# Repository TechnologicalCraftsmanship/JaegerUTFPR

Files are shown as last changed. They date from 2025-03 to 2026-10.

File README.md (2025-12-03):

# Jaeger UTFPR Project Repository

This repository organizes all project files related to the **Jaeger** system, developed as part of ongoing research at **UTFPR**. It includes mechanical parts, electronic fabrication files, embedded system workspaces, and a VR application.

---

## 📂 Folder Structure

.

├── 3d_Models

│   └── models

├── Fabrication

│   ├── Jaeger_5_Rev1

│   │   └── gerber

│   └── Jaeger_Driver_3_Rev1

│       └── gerber

├── JaegerUTFPR_Workspace

│   └── MainProject

└── VR_Application

---

## 📁 Folder Descriptions

### `3d_Models/`
Contains all mechanical 3D models designed for the project that must be printed.

- `models/`: Subfolder holding specific 3D models

---

### `Fabrication/`
Houses the PCB designs and manufacturing files for the Jaeger hardware components.

- `Jaeger_5_Rev1/`: Files related to **Jaeger 5 Revision 1**, which include schematic diagrams and layout files.
  - `gerber/`: Exported Gerber files for PCB fabrication of **Jaeger 5 Rev1**.
  
- `Jaeger_Driver_3_Rev1/`: Files related to **Jaeger Driver 3 Revision 1**, responsible for driving specific modules or actuators.
  - `gerber/`: Exported Gerber files for PCB fabrication of **Jaeger Driver 3 Rev1**.

---

### `JaegerUTFPR_Workspace/`
This folder is the workspace for embedded development, using ESP-IDF.

- `MainProject/`: The main embedded firmware source code, configuration files, and dependencies for the Jaeger system.

---

### `VR_Application/`

Contains the virtual reality application developed for project visualization, simulation, or remote monitoring. This include **Unity** project files, assets, and scripts for interacting with the Jaeger system in a 3D environment.

---

## 🚀 Purpose
This repository aims to centralize all essential components of the Jaeger project, ensuring easy access and version control across mechanical design, hardware development, firmware programming, and VR visualization.

---

## 📝 License

This project is licensed under the [MIT License](LICENSE).

## 📚 Citation

If you use this project or the Jaeger system in your research, please cite the following paper:

> Monteiro et al., "Design and implementation of an open-source, low-cost remote-controlled tiny humanoid robot for accessible robotics applications," *Robotica*, pp. 1–18, 2025.  
> **DOI:** [https://doi.org/10.1017/S0263574725102907](https://doi.org/10.1017/S0263574725102907)

**BibTeX:**

```bibtex
@article{Monteiro2025,
  title={Design and implementation of an open-source, low-cost remote-controlled tiny humanoid robot for accessible robotics applications},
  author={Pivaro Monteiro, Marcos Eduardo and dos Santos, Eduardo Nunes and Pigatto, Daniel Fernando and Alves Junior, Joilson and Ramalho, Leonardo Lira and Issicaba, Diego},
  journal={Robotica},
  year={2025},
  pages={1–18},
  doi={10.1017/S0263574725102907}
}

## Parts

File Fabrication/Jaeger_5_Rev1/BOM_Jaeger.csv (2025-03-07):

ID | Name | Designator | Footprint | Quantity | Manufacturer Part | Manufacturer | Supplier | Supplier Part | Price
1 | B2B-XH-A | X1 | B2B-XH-A | 1
2 | OV2640 FPC | FPC1 | OV2640 FPC 24P | 1 | AFC01-S24FCA-00 | JUSHUO | LCSC | C262669 | 0.113
3 | 1.25T-1-2AW | MIC,SPK | CONN-TH_1.25T-1-2AW | 2 | 1.25T-2AW | BOOMELE(博穆精密) | LCSC | C10832 | 0.015
4 | 220uF | C23,C24 | CAP-TH_BD5.0-P2.00-D0.8-FD | 2 | SK100M035B070A | CapXon | LCSC | C62931 | 0.015
5 | 100uF | C5 | CAP-TH_BD5.0-P2.00-D0.8-FD | 1 | SK100M035B070A | CapXon | LCSC | C62931 | 0.015
6 | 0 | R17 | R0603 | 1 | PTFR0603B10K0P9 | ResistorToday | LCSC | C328421 | 0.107
7 | 15pF | C12 | C0603 | 1 | 10uF | Samsung Electro-Mechanics | LCSC | C15415
8 | 0.1uF | C19,C11,C14,C17,C18,C20,C22,C6,C8,C10,C13 | C0603 | 11 | 10uF | Samsung Electro-Mechanics | LCSC | C15415
9 | ESP32-WROOM-32DC | U1 | WIFIM-SMD_38P-L25.5-W18.0-P1.27 | 1 | ESP32-WROOM-32DC | Espressif Systems | LCSC | C473013
10 | APS6404L-3SQR | U5 | SOP-8_L4.9-W3.9-P1.27-LS6.0-BL | 1 | APS6404L-3SQR | apmemory | LCSC | C9900003441
11 | 10uF | C1,C2,C16,C15,C3,C4,C7 | C0603 | 7 | 10uF | Samsung Electro-Mechanics | LCSC | C15415
12 | 10K | R6,R7,R16,R12,R13,R14,R3,R1 | R0603 | 8 | PTFR0603B10K0P9 | ResistorToday | LCSC | C328421 | 0.107
13 | Button-SMD | RST | SW-SMD_4P-L5.2-W5.2-P3.70-LS6.5 | 1 | 4*4*1.5Copper head,260G, 0.25mm, | BBJ | LCSC | C71830
14 | AMS1117-3.3 | U2,U6 | SOT-223-3_L6.5-W3.4-P2.30-LS7.0-BR | 2 | AMS1117-3.3 | AMS | LCSC | C6186 | 0.153
15 | 4.7K | R4,R5 | R0603 | 2 | PTFR0603B10K0P9 | ResistorToday | LCSC | C328421 | 0.107
16 | 0.1Ohm | R8,R9 | R0603 | 2 | PTFR0603B10K0P9 | ResistorToday | LCSC | C328421 | 0.107
17 | Header-Male-2.54_1x5 | H3 | HEADER-MALE-2.54_1X5 | 1
18 | AO3401A | Q2,Q1 | SOT-23-3_L2.9-W1.6-P1.90-LS2.8-BR | 2 | FDN340P | FAIRCHILD | LCSC | C75469 | 0.166
19 | 1uF | C9,C21 | C0603 | 2 | 10uF | Samsung Electro-Mechanics | LCSC | C15415
20 | 100K | R10 | R0603 | 1 | PTFR0603B10K0P9 | ResistorToday | LCSC | C328421 | 0.107
21 | 1K | R11 | R0603 | 1 | PTFR0603B10K0P9 | ResistorToday | LCSC | C328421 | 0.107
22 | LM358 | U9 | SOP-8_L4.9-W3.9-P1.27-LS6.0-BL | 1 | LM358 | KEXIN(科信) | LCSC | C369938 | 0.052
23 | 3.6 ZMM | D1 | LL-34_L3.5-W1.5-RD | 1 | ZMM22-M | ST(先科) | LCSC | C8073 | 0.018
24 | 1K | R2,R15 | R0603 | 2 | AECR0603F1R00T9 | ResistorToday | LCSC | C328344 | 0.001
25 | XC6206P282MR | U3 | SOT-23-3_L2.9-W1.6-P1.90-LS2.8-BR | 1 | XC6206P282MR | TOREX | LCSC | C14255 | 0.115
26 | XC6206P122MR | U4 | SOT-23-3_L2.9-W1.6-P1.90-LS2.8-BR | 1 | XC6206P122MR-G | Torex Semicon | LCSC | C424699 | 0.114
27 | Header-Male-2.54_1x8 | H1 | HDR-TH_8P-P2.54-V-M | 1 | 210S-1*8P L=11.6MMGold-plated black | Ckmtw | LCSC | C124381 | 0.068

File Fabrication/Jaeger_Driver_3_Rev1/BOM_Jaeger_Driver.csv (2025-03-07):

ID | Name | Designator | Footprint | Quantity | Manufacturer Part | Manufacturer | Supplier | Supplier Part | Price
1 | SH 1mm | H4,H7,H8,H1,H6,H3,H5 | SMD-1.0MM-4P-JST-H2.9 | 7 | SH 1.0mm 4P connector |  | Digi-Key
2 | 1.25T-1-8AW | H3_4,H6_1,H6_7 | CONN-TH_8P-P1.25_1.25T-1-8AW | 3 | 1.25T-1-8AW | BOOMELE | LCSC | C10838 | 0.043
3 | B2B-PH | J2_1,J2_2 | B2B-PH-K-S | 2 | - | JST Sales America | RS-Online
4 | Header-Male-2.54_1x8 | J1 | HDR-TH_8P-P2.54-V-M | 1 | 210S-1*8P L=11.6MMGold-plated black | Ckmtw | LCSC | C124381 | 0.068
5 | 100uF | C25 | CAP-TH_BD5.0-P2.00-D0.8-FD | 1 | SK100M035B070A | CapXon | LCSC | C62931 | 0.015
6 | 10uF | C16,C13,C22,C19,C10,C7,C4,C2 | C0603 | 8 | C0603C104K3NACAUTO | KEMET | LCSC | C141256 | 0.023
7 | 0.01uF | C14,C23,C20,C17,C11,C8,C5,C1 | C0603 | 8 | C0603C104K3NACAUTO | KEMET | LCSC | C141256 | 0.023
8 | 2.2uF | C15,C24,C21,C18,C12,C9,C6,C3 | C0603 | 8 | C0603C104K3NACAUTO | KEMET | LCSC | C141256 | 0.023
9 | DRV8833 | U5,U8,U7,U6,U4,U3,U2,U1 | TSSOP-16EP | 8 | DRV8833PWPR | Texas Instruments | LCSC | C50506 | 0.7
10 | AO3401A | Q16,Q15,Q14,Q13,Q12,Q11,Q10,Q9,Q8,Q7,Q6,Q5,Q3,Q2,Q1 | SOT-23-3_L2.9-W1.6-P1.90-LS2.8-BR_PADSHORT | 15 | FDN340P | FAIRCHILD | LCSC | C75469 | 0.166
11 | AO3401A | Q4 | SOT-23-3_L2.9-W1.6-P1.90-LS2.8-BR_PADSHORT | 1 | FDN340P | onsemi(安森美) | LCSC | C75469 | 0.166
12 | B2B-XH-A | X1 | B2B-XH-A | 1
13 | 0.1Ohm | R9,R1 | R0603 | 2 | PTFR0603B10K0P9 | ResistorToday | LCSC | C328421 | 0.107
14 | 10uF | C26,C29,C27 | C0603 | 3 | 10uF | Samsung Electro-Mechanics | LCSC | C15415
15 | 74HC259D | U9,U11,U10 | SOIC-16_L9.9-W3.9-P1.27-LS6.0-BL | 3 | 74HC259D,652 | Nexperia | LCSC | C546779 | 0.4
16 | AMS1117-5 | U15,U16 | SOT-223-3_L6.5-W3.4-P2.30-LS7.0-BR | 2 | AMS1117-3.3 | AMS | LCSC | C6186 | 0.153

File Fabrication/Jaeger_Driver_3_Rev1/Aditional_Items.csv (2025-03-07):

ID | Name | Reference Link | Quantity
1 | Stepper Motor | https://www.aliexpress.com/item/1005001636602660.html | 7
2 | N20 60rpm DC Motor with reduction | https://www.aliexpress.com/item/1005002870346214.html | 2
3 | OV2640 160deg. Camera. | https://www.aliexpress.com/item/1005004852494122.html | 1
4 | Header-Male-2.54_1x8 | https://www.aliexpress.com/item/32933150164.html | 1
5 | Switch - 10*15mm SPST 2PIN | https://www.aliexpress.com/item/32933150164.html | 1
6 | 16340 Battery Slot | https://www.aliexpress.com/item/1005004821679671.html | 2
7 | 9x7mm Microphone | https://www.aliexpress.com/item/32951244243.html | 1
8 | 2.3cm 2W Speaker | https://www.aliexpress.com/item/32859997207.html | 1

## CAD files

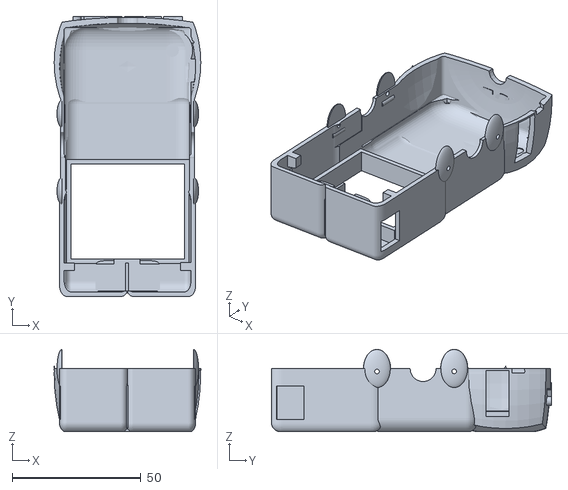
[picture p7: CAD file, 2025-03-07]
3d_Models/models/base_back.stl
57.0 x 108.8 x 32.0

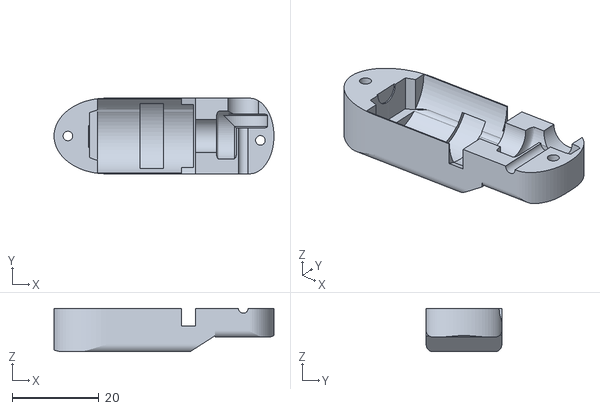
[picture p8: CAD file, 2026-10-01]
3d_Models/models_1.0/arm_left_1.stl
50.6 x 17.4 x 10.00

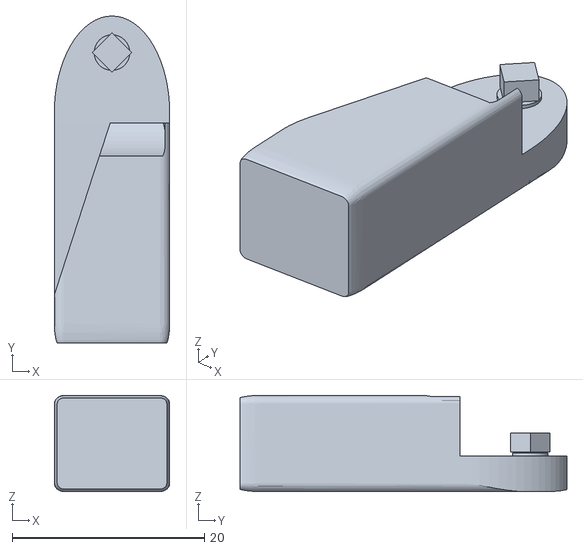
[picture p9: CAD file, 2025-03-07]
3d_Models/models/forearm_left.stl
12.0 x 34.0 x 10.0

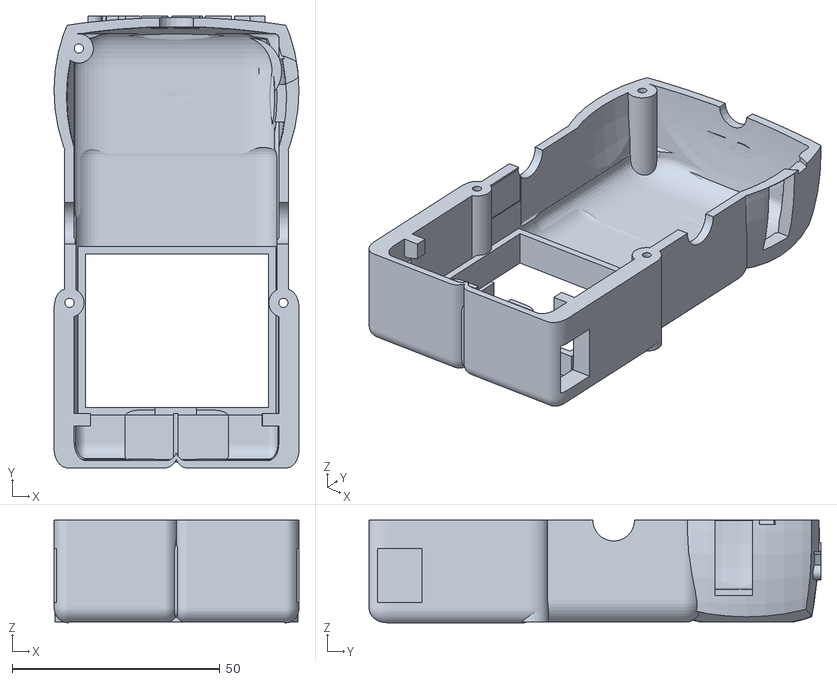
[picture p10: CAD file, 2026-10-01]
3d_Models/models_1.0/base_back.stl
59.0 x 108.8 x 24.7

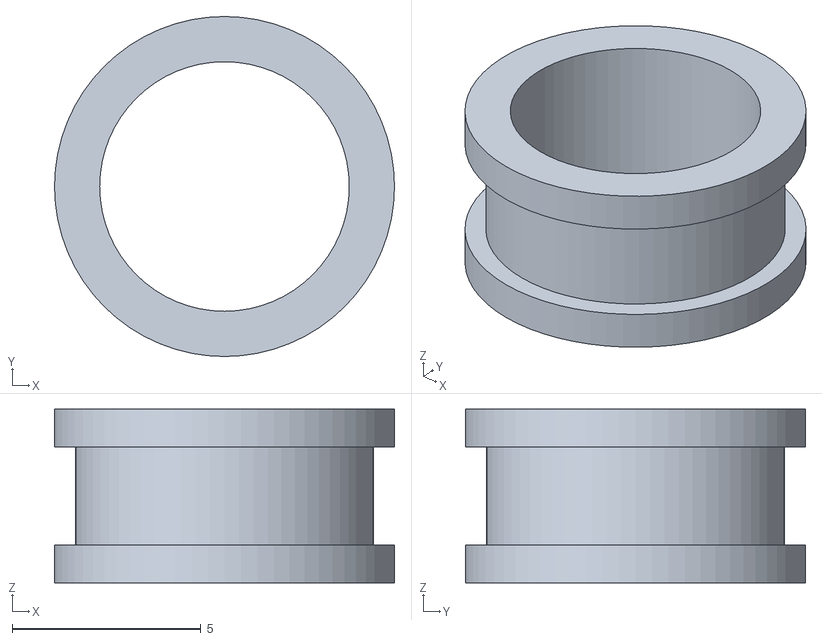
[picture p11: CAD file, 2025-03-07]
3d_Models/models/antenna_support.stl
9.00 x 9.00 x 4.60

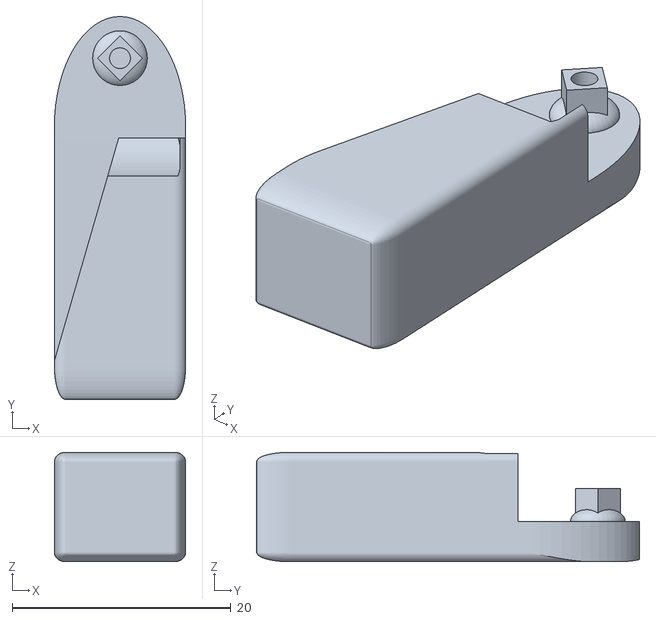
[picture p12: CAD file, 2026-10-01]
3d_Models/models_1.0/forearm_left.stl
12.0 x 35.0 x 10.0

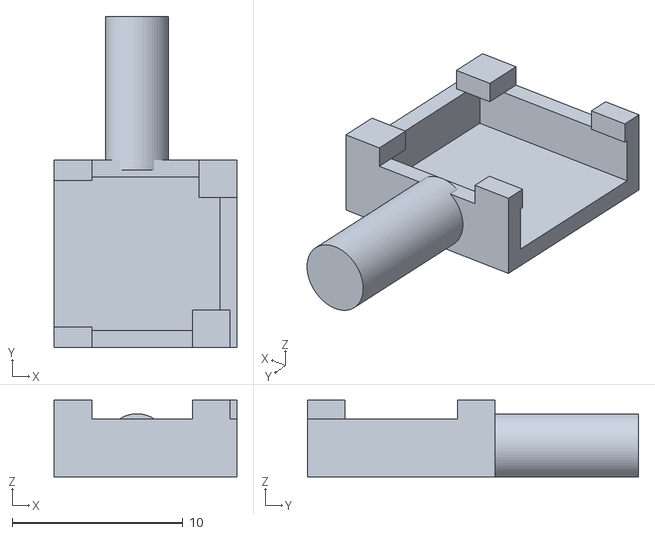
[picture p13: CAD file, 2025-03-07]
3d_Models/models/cam_holder.stl
10.7 x 19.4 x 4.50

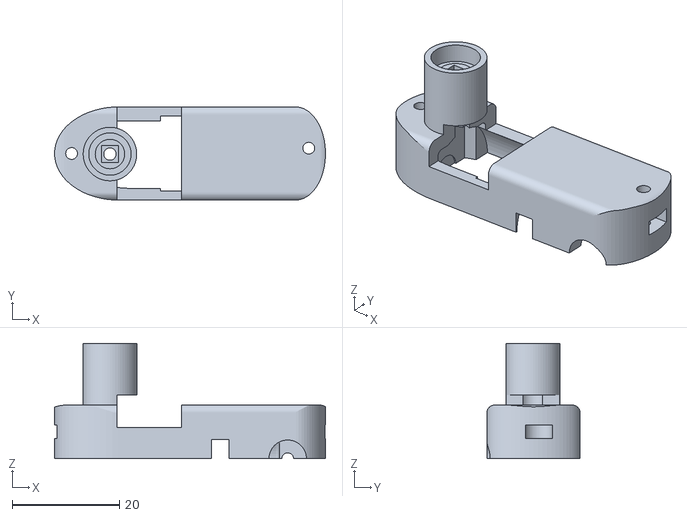
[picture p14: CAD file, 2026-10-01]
3d_Models/models_1.0/arm_right_2.stl
50.6 x 17.4 x 21.5

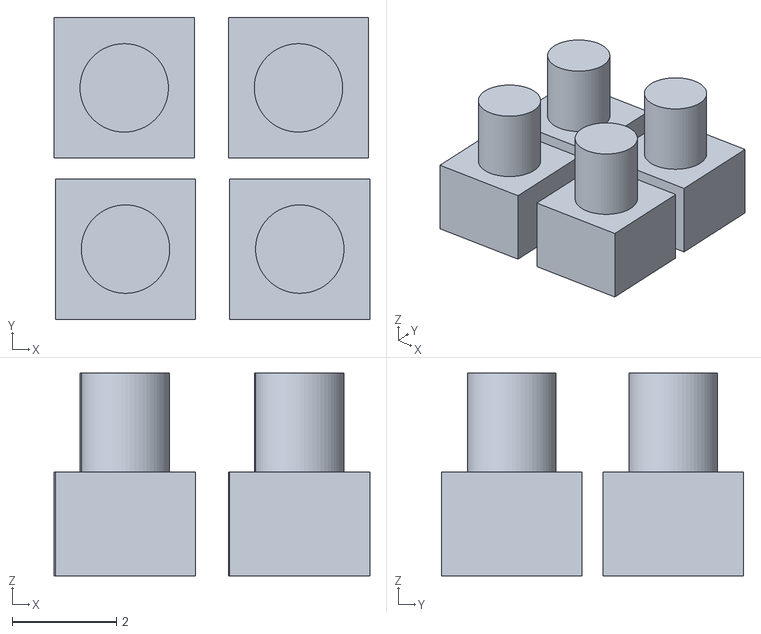
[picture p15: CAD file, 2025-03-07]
3d_Models/models/motor_repair_4x.stl
6.08 x 5.80 x 3.90

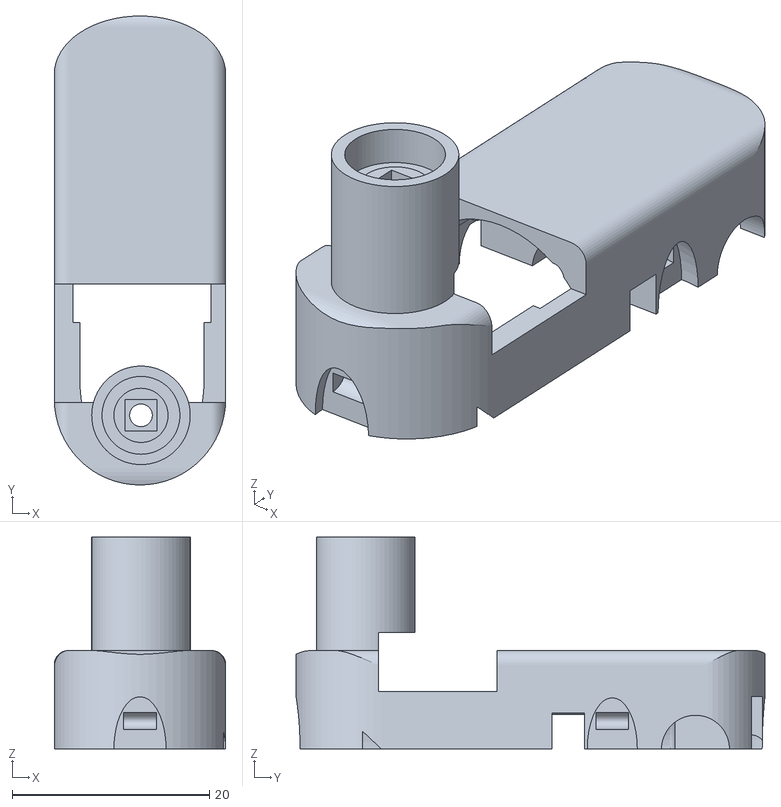
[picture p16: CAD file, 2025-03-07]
3d_Models/models/arm_right_2.stl
17.4 x 47.6 x 21.5

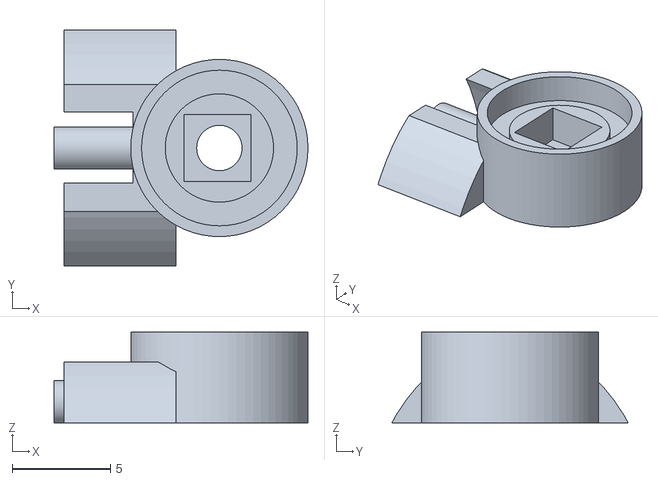
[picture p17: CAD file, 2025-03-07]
3d_Models/models/conForearm.stl
12.9 x 12.0 x 4.60

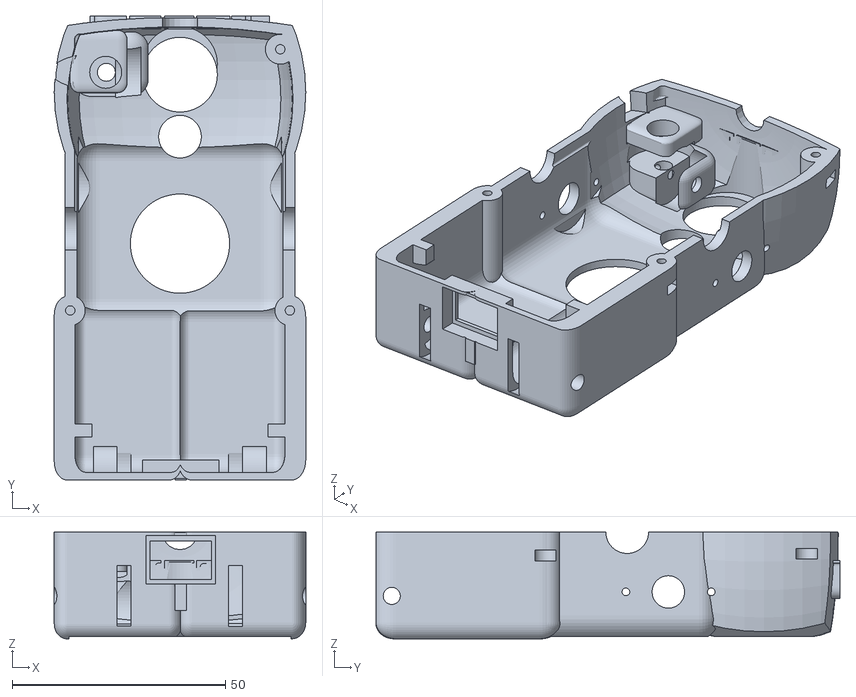
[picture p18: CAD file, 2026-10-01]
3d_Models/models_1.0/base_front.stl
59.0 x 108.8 x 25.0

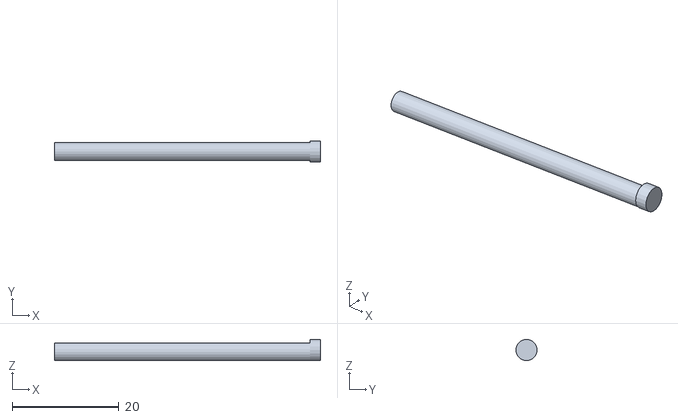
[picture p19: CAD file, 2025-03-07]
3d_Models/models/conWheels.stl
49.8 x 4.00 x 4.00

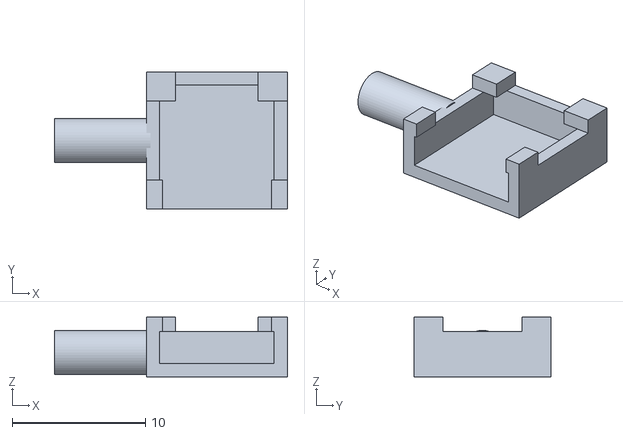
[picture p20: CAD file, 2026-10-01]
3d_Models/models_1.0/cam_holder.stl
17.5 x 10.3 x 4.50

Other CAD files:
3d_Models/models_1.0/arm_left_2.stl
3d_Models/models_1.0/arm_right_1.stl
3d_Models/models_1.0/forearm_right.stl
3d_Models/models/forearm_right.stl
3d_Models/models/arm_left_1.stl
3d_Models/models/arm_left_2.stl
3d_Models/models/arm_right_1.stl
3d_Models/models/base_front.stl
3d_Models/models/cam_holder_wheel.stl
3d_Models/models/cam_mot_wheel.stl
3d_Models/models/wheels.stl

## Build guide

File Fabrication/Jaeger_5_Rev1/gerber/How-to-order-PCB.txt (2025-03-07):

How to Order PCB

Please refer to:
https://docs.easyeda.com/en/PCB/Order-PCB

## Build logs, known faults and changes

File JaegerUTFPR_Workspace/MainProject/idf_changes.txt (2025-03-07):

Não funcionou:
//C:/Espressif/frameworks/esp-idf-v4.4.4\components\lwip\port\esp32\netif\wlanif.c(87): netif->mtu = 4400;
//C:/Espressif/frameworks/esp-idf-v4.4.4\components\lwip\port\esp32\netif\ethernetif.c(83): netif->mtu = 4400;
//C:/Espressif/frameworks/esp-idf-v4.4.4\components\lwip\lwip\src\netif\bridgeif.c(497): netif->mtu = 4400;
//C:/Espressif/frameworks/esp-idf-v4.4.4\components\lwip\lwip\src\netif\slipif.c(79): #define SLIP_MAX_SIZE 4400

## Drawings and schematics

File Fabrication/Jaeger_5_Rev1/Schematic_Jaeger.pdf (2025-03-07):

Microcontroller | Camera Header

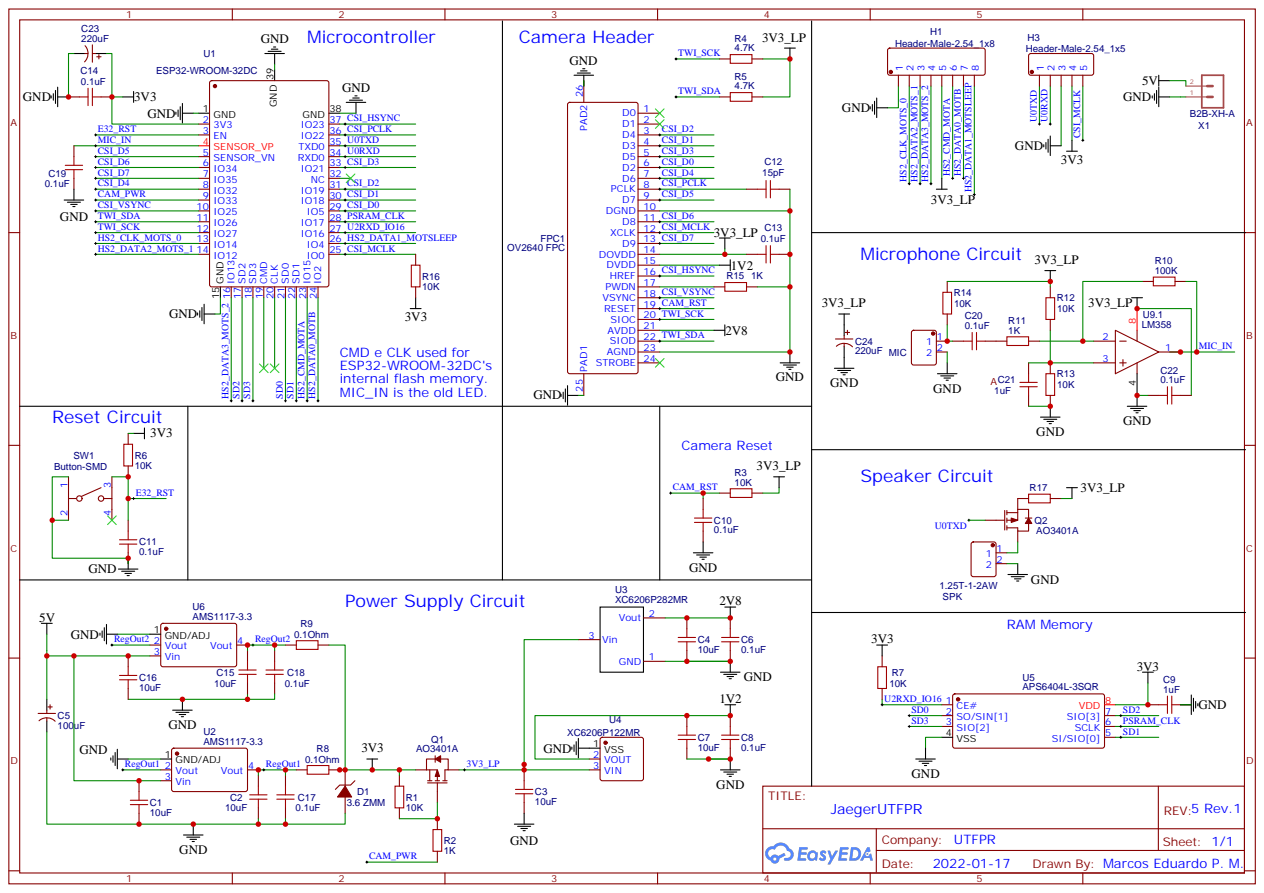
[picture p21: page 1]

IO0 25 IO² 24 IO¹⁵ 23 SD¹ 22 SD⁰ 21 CLK 20 CMD 19 SD³ 18 SD² 17 IO¹³ 16 GND 15

HS2_CMD_MOTA
CMD e CLK used for
ESP32-WROOM-32DC's
internal flash memory.
MIC_IN is the old LED.

Drawn By: Marcos Eduardo P. M.

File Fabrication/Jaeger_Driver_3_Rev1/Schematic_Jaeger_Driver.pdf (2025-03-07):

Motor 1 | Motor 2

# Motor 3

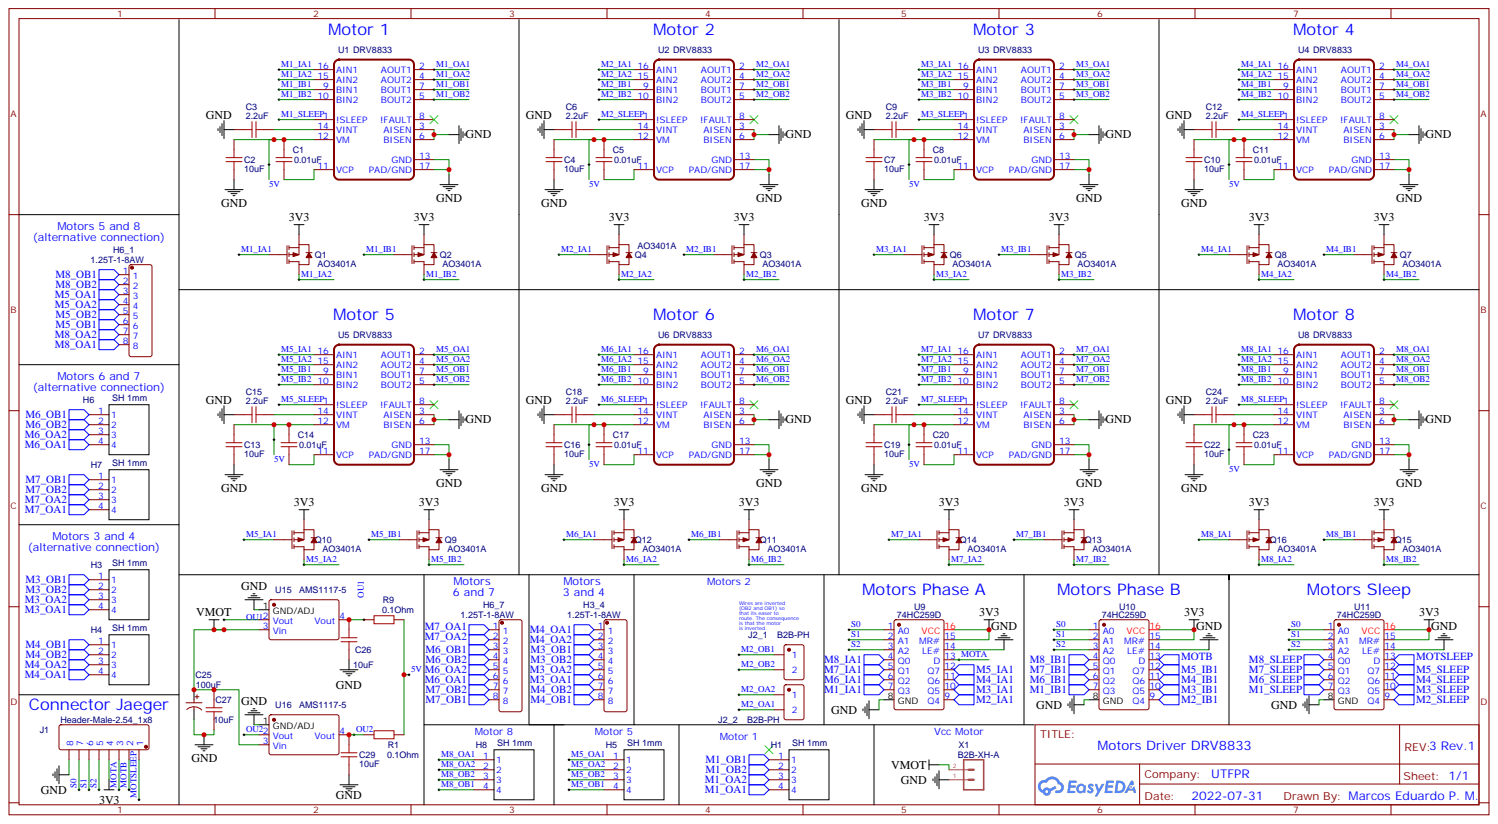
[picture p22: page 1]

Wires are inverted
(OB2 and OB1) so
that its easer to
route. The consequence
is that the motor
is inverted.

Drawn By: Marcos Eduardo P. M.

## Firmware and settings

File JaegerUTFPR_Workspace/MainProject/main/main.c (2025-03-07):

/**
 * This example takes a picture every 5s and print its size on serial monitor.
 */

// =============================== SETUP ======================================

// 1. Board setup (Uncomment):
// #define BOARD_WROVER_KIT
// #define BOARD_ESP32CAM_AITHINKER

/**
 * 2. Kconfig setup
 *
 * If you have a Kconfig file, copy the content from
 *  https://github.com/espressif/esp32-camera/blob/master/Kconfig into it.
 * In case you haven't, copy and paste this Kconfig file inside the src directory.
 * This Kconfig file has definitions that allows more control over the camera and
 * how it will be initialized.
 */

/**
 * 3. Enable PSRAM on sdkconfig:
 *
 * CONFIG_ESP32_SPIRAM_SUPPORT=y
 *
 * More info on
 * https://docs.espressif.com/projects/esp-idf/en/latest/esp32/api-reference/kconfig.html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
 */

// ================================ CODE ======================================
#include <esp_log.h>
#include "esp_wifi.h"
#include <esp_system.h>
#include "esp_event.h"
#include <nvs_flash.h>
#include <sys/param.h>
#include "driver/gpio.h"
#include <string.h>

#include "freertos/FreeRTOS.h"
#include "freertos/task.h"
#include "tcpip_adapter_types.h"
#include "protocol_examples_common.h"

// support IDF 5.x
#ifndef portTICK_RATE_MS
#define portTICK_RATE_MS portTICK_PERIOD_MS
#endif

#include "main_project.h"
#include "DataArray.h"
#include "speaker.h"
#include "mic.h"
#include "esp_camera.h"

extern void startCameraServer();
int soundActive = 1;

volatile Connected connected = DISCONNECTED;
char conBuffer[MAX_PACKET];

#if SPEAKER_ON && SPEAKER_RMT
	rmt_speaker_t rmtSpeaker;
#endif

static const char *TAG = "main";

static camera_config_t camera_config = {
    .pin_pwdn = CAM_PIN_PWDN,
    .pin_reset = CAM_PIN_RESET,
    .pin_xclk = CAM_PIN_XCLK,
    .pin_sscb_sda = CAM_PIN_SIOD,
    .pin_sscb_scl = CAM_PIN_SIOC,

    .pin_d7 = CAM_PIN_D7,
    .pin_d6 = CAM_PIN_D6,
    .pin_d5 = CAM_PIN_D5,
    .pin_d4 = CAM_PIN_D4, //Fixed using define @ main_project.h
    .pin_d3 = CAM_PIN_D3,
    .pin_d2 = CAM_PIN_D2,
    .pin_d1 = CAM_PIN_D1,
    .pin_d0 = CAM_PIN_D0,
    .pin_vsync = CAM_PIN_VSYNC,
    .pin_href = CAM_PIN_HREF,
    .pin_pclk = CAM_PIN_PCLK,

    //XCLK 20MHz or 10MHz for OV2640 double FPS (Experimental)
    .xclk_freq_hz = 20000000,
    //.ledc_timer = LEDC_TIMER_0,
    //.ledc_channel = LEDC_CHANNEL_0,

    //.pixel_format = PIXFORMAT_RGB565, //YUV422,GRAYSCALE,RGB565,JPEG
    .pixel_format   = PIXFORMAT_JPEG,
    .frame_size = FRAMESIZE_SVGA, // 800x600 //FRAMESIZE_SVGA,    //QQVGA-UXGA Do not use sizes above QVGA when not JPEG

    .jpeg_quality = 9, //0-63 lower number means higher quality
	//5 = ~48kb
	//9 = ~19kb
    .fb_count = 2,       //if more than one, i2s runs in continuous mode. Use only with JPEG
    .grab_mode = CAMERA_GRAB_WHEN_EMPTY,
};

static esp_err_t init_camera()
{
    //initialize the camera
    esp_err_t err = esp_camera_init(&camera_config);
    if (err != ESP_OK)
    {
    	//_ESP_LOGI(TAG, "Camera Init Failed");
        return err;
    }
    //LOG_LOCAL_LEVEL //_ESP_LOG_VERBOSE

    return ESP_OK;
}

static void event_handler(void* arg, esp_event_base_t event_base,
                                int32_t event_id, void* event_data)
{
    if (event_base == WIFI_EVENT && event_id == WIFI_EVENT_STA_START) {
        esp_wifi_connect();
    } else if (event_base == WIFI_EVENT && event_id == WIFI_EVENT_STA_DISCONNECTED) {
        esp_wifi_connect();
    } else if (event_base == IP_EVENT && event_id == IP_EVENT_STA_GOT_IP) {
        ip_event_got_ip_t* event = (ip_event_got_ip_t*) event_data;
        //_ESP_LOGI(TAG, "got ip:" IPSTR, IP2STR(&event->ip_info.ip));
    }
}
void setLowPowerPin(uint8_t enable)
{
    gpio_set_direction(CAM_PIN_PWDN, GPIO_MODE_OUTPUT);
    gpio_set_level(CAM_PIN_PWDN, enable); //P-channel: 0 means On and 1 means Off
}
void playTestSound();
void app_main()
{

	//#undef SPEAKER_ON
	//#undef MIC_ON
	//redefine pref. IP to Local
	//@ sdkconfig
	//# CONFIG_EXAMPLE_CONNECT_IPV6_PREF_LOCAL_LINK is not set
	//CONFIG_EXAMPLE_CONNECT_IPV6_PREF_GLOBAL=y

	//@ main_project.h
	////#define CONFIG_EXAMPLE_IPV6 1



	//playTestSound();
	soundActive = 1;

	int cameraStarted = 0;
    //nvs_flash_init();
    //tcpip_adapter_init();

    ////_printf(("1....");
	//Turn off the low power pin so we can use the camera, motors and other resources.
	setLowPowerPin(0);

	//The first thing we must do after turning on VCC motors (and camera) pin is to init the motors so that we make sure they are off
    motorInit();


	///*
	//First, we disable the speaker pin just to make sure it wont be on by default
	forceSpeakerDisable();
	#if SPEAKER_ON && SPEAKER_LEDC
		DataArray speakerArray;
	    dataArrayInit(&speakerArray, SPEAKER_ARRAY_MAX);
	#endif

	#ifdef MIC_ON
	    //Sound Configurations
		DataArray micArray;
		PROJECT_DATA_TYPE *micRawData = malloc(4000);
	    //configure the Mic array and the Speaker Array
	    dataArrayInit(&micArray, MIC_ARRAY_MAX);
	#endif


    ESP_ERROR_CHECK(nvs_flash_init());
	////_printf(("5....");
    ESP_ERROR_CHECK(esp_netif_init());
	////_printf(("6....");

    ESP_ERROR_CHECK(esp_event_loop_init(event_handler, NULL) );
	////_printf(("7....");
    ESP_ERROR_CHECK(example_connect());
	////_printf(("8....");


    if(ESP_OK != init_camera()) {
    	//_ESP_LOGE(TAG, "Camera Failed.\n");
    	cameraStarted = 0;

        ////_ESP_LOGI(TAG, "Camera Ready! Use 'http://");
        //tcpip_adapter_ip_info_t adapterInfo;

        //tcpip_adapter_get_ip_info(0, &adapterInfo); //TCPIP_ADAPTERE_IF_STA = 0
        //char *ip = (char *)&adapterInfo.ip;
        ////_printf((WiFi.localIP());
        ////_ESP_LOGI(TAG, "%d . %d . %d , %d", ip[0], ip[1], ip[2], ip[3]);
        ////_ESP_LOGI(TAG, "' to connect");

        //return;
    } else {
    	cameraStarted = 1;
    }

    start_server();


//*/

    //esp_log_level_set("*", //_ESP_LOG_VERBOSE);

    /*//test with a default sound
    adjustSound(tmpSound, sizeof(tmpSound)/sizeof(SPEAKER_DATA_TYPE));
    dataArrayClearData(&micArray);
    dataArrayWriteFromArrayUINT8_T(&micArray, tmpSound, sizeof(tmpSound)/sizeof(SPEAKER_DATA_TYPE));
	//*/

	#if SPEAKER_ON && SPEAKER_LEDC
    	esp_log_level_set("*", ESP_LOG_ERROR);
			//Configure the LEDC PWM
			initSpeaker(&speakerArray);
	#endif
	#if SPEAKER_ON && SPEAKER_RMT
		//Configure the LEDC PWM
		initSpeaker(&rmtSpeaker);
		//playTestSound(&rmtSpeaker);
		//vTaskDelay(pdMS_TO_TICKS(1000));

    	esp_log_level_set("*", ESP_LOG_ERROR);
#if SPEAKER_PIN ==1 || SPEAKER_PIN ==3
#else
		//esp_log_level_set("*", ESP_LOG_INFO);
#endif
	#endif

	#ifdef MIC_ON
	    //Create the mic task
	    createMicrophoneTask(&micArray);
	#endif

    int64_t fr_start = 0;
    int64_t fr_end = 0;
    int64_t frame_time;


    //int64_t lastExecution = 0;




    while (1)
    {

    	//Sleep in order to let other tasks to process
		vTaskDelay(pdMS_TO_TICKS(40));

    	//if there are free timers
    	if(motorAvailableTimers > 0)
    		verifyMotorQueue();
    	//
        if(connected == CONNECTED)
        {
        	//pastMs += 1000/portTICK_RATE_MS;
///*
#if SPEAKER_ON && SPEAKER_RMT
        	if(soundActive) //only play if the sound is on
        	{
				if(verifyPlaySound(&rmtSpeaker, false))
				{
					//playing sound
				}
        	}
#endif
#ifdef MIC_ON

        	//if we have the sound active and
        	//if there is enough mic data available to send
        	if(soundActive && !playingSound && dataArrayElementsToRead(&micArray) > MIC_SAMPLES_TO_SEND)
        	{
        		////_ESP_LOGI(TAG, "Sending MIC data.");
        		//pastMs = 0;
        		dataArrayReadToArray(&micArray, micRawData, MIC_SAMPLES_TO_SEND);
        		sendRawData(SOUND, micRawData, MIC_SAMPLES_TO_SEND);
        		//continue;
        	}
#endif

        	if(cameraStarted)
        	{
				fr_start = esp_timer_get_time();
				camera_fb_t *pic = esp_camera_fb_get();
				if(pic)
				{
					ESP_LOGI(TAG, "Image start sending.");
					sendCameraImage((void*)pic, 1);
					esp_camera_fb_return(pic);
					ESP_LOGI(TAG, "Image sent.");
					//lastExecution = esp_timer_get_time();
	//				fr_end = esp_timer_get_time();
	//				frame_time = (fr_end - fr_start)/1000;
	//				// use pic->buf to access the image
	//				//_ESP_LOGI(TAG, "%zu with %.1ffps", pic->len, 1000.0 / (uint32_t)frame_time);
				} else {
					ESP_LOGI(TAG, "Could not get image.");
				}
        	}
        } else {
        	vTaskDelay(1000 / portTICK_RATE_MS);
        }
    }
#if SPEAKER_ON && SPEAKER_RMT
    deinitSpeaker(&rmtSpeaker);
#endif
#ifdef MIC_ON
    free(micRawData);
#endif
    motorDeinit();
}

/*
 *
#include "freertos/FreeRTOS.h"
#include "esp_wifi.h"
#include "esp_system.h"
#include "esp_event.h"
#include "esp_event_loop.h"
#include "nvs_flash.h"
#include "driver/gpio.h"
#include "esp_camera.h"

esp_err_t event_handler(void *ctx, system_event_t *event)
{
    return ESP_OK;
}

void app_main(void)
{
    nvs_flash_init();
    tcpip_adapter_init();
    ESP_ERROR_CHECK( esp_event_loop_init(event_handler, NULL) );
    wifi_init_config_t cfg = WIFI_INIT_CONFIG_DEFAULT();
    ESP_ERROR_CHECK( esp_wifi_init(&cfg) );
    ESP_ERROR_CHECK( esp_wifi_set_storage(WIFI_STORAGE_RAM) );
    ESP_ERROR_CHECK( esp_wifi_set_mode(WIFI_MODE_STA) );
    wifi_config_t sta_config = {
        .sta = {
            .ssid = CONFIG_ESP_WIFI_SSID,
            .password = CONFIG_ESP_WIFI_PASSWORD,
            .bssid_set = false
        }
    };

    ESP_ERROR_CHECK( esp_wifi_set_config(WIFI_IF_STA, &sta_config) );
    ESP_ERROR_CHECK( esp_wifi_start() );

    ESP_ERROR_CHECK( esp_wifi_connect() );

    gpio_set_direction(GPIO_NUM_4, GPIO_MODE_OUTPUT);
    int level = 0;
    while (true) {
        gpio_set_level(GPIO_NUM_4, level);
        level = !level;
        vTaskDelay(300 / portTICK_PERIOD_MS);
    }
}

*/

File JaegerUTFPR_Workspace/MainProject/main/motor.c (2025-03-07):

/*
 * Motor.c
 *
 *  Created on: Feb 28, 2022
 *      Author: Thoughtful
 */
#include "sdkconfig.h"
#include "freertos/FreeRTOS.h"
#include "freertos/task.h"
#include "esp_log.h"
#include "esp_wifi.h"
#include "esp_system.h"
#include "esp_event.h"
#include "esp_event_loop.h"
#include "nvs_flash.h"
#include "driver/gpio.h"
#include "hal/gpio_types.h"
//#include "./managed_components/espressif__esp32-camera/driver/include/esp_camera.h"

#include "esp_camera.h"
#include "main_project.h"
#include "driver/rmt.h"
#include "driver/timer.h"

//#include "freertos/semphr.h"

/*

#define DIR_PORT 2
#define STEP_PORT 4
#define MOTOR_SEL0_PORT GPIO_NUM_14
#define MOTOR_SEL1_PORT GPIO_NUM_12
#define MOTOR_SEL2_PORT GPIO_NUM_13
#define MOTOR_SEL3_PORT GPIO_NUM_15
*/

static portMUX_TYPE motorsLock = portMUX_INITIALIZER_UNLOCKED;

static const char *TAG = "motor";

typedef struct MotorTimerTask
{
	bool enabled;
	timer_group_t groupId;
	timer_idx_t timerId;
	int motorId;
	int direction; //1 or -1
	//int ISRSet;
	uint32_t currentStep;
	uint32_t totalSteps;
	uint32_t stepSlowingDown;
	uint32_t initialTimerCount;
	uint32_t currentTimerCount;
	int dcCyclesOn; //used only for DC Motors
	int dcCyclesOff; //used only for DC Motors
	int valueLeftleg; //used only for DC Motors
	int valueRightLeg; //used only for DC Motors
} MotorTimerTask;

#if MOTOR_VERSION == 1
static const float steps_per_rev[12] =
{
		1,  //Used to obtain the information for the left leg
		20 * 165.3817f, //Camera Motor, no reduction
		1,  //DC motors, Used to obtain the information for the right leg
		20 * 165.3817f,
		20 * 165.3817f,
		2210,
		20 * 165.3817f,
		20 * 165.3817f,
		2210,
		1, //Not used
		1 //Not used
};

static const int32_t motorDefaultDirection[12] =
{
		-1,  //Used to obtain the information for the left leg
		1, //Camera Motor
		1,  //DC motor right leg, Used to obtain the information for the right leg
		1, //second motor, right
		-1, //first motor, right arm closer to the shoulder
		-1, //right arm
		-1, //second motor, left arm
		1, //first motor, left arm closer to the shoulder
		1, //left arm
		0, //Not used
		0 //Not used
};
#elif MOTOR_VERSION == 2

static const float steps_per_rev[12] =
{
		1,  //Used to obtain the information for the left leg
		20 * 165.3817f, //Camera Motor, no reduction
		1,  //DC motors, Used to obtain the information for the right leg
		20 * 165.3817f,
		2210,
		2210,
		20 * 165.3817f,
		2210,
		2210,
		1, //Not used
		1 //Not used
};

static const int32_t motorDefaultDirection[12] =
{
		-1,  //Used to obtain the information for the left leg
		1, //Camera Motor
		1,  //DC motor right leg, Used to obtain the information for the right leg
		1, //second motor, right
		-1, //first motor, right arm closer to the shoulder
		-1, //right arm
		-1, //second motor, left arm
		1, //first motor, left arm closer to the shoulder
		1, //left arm
		0, //Not used
		0 //Not used
};
#elif MOTOR_VERSION == 3

static const float steps_per_rev[12] =
{
		1,  //Used to obtain the information for the left leg -> MOTA_PIN -> J2_2
		2210, //Camera Motor
		1,  //DC motors, Used to obtain the information for the right leg -> MOTB_PIN -> J2_1
		2210, //Right Forearm
		2210, //Right arm
		2210, //Right arm, closer to the shoulder
		2210, //Left Forearm
		2210, //Left arm,
		2210, //Left arm, closer to the shoulder
		1, //Not used
		1 //Not used
};

static const int32_t motorDefaultDirection[12] =
{
		-1,  //Used to obtain the information for the left leg
		1, //Camera Motor
		1,  //DC motor right leg, Used to obtain the information for the right leg
		-1,
		-1,
		-1,
		1,
		1,
		1,
		0, //Not used
		0 //Not used
};
#endif

//State of all motors
Motor motors[TOTAL_MOTORS] = { 0 } ;

PinMask motorDirection[MAX_DIRECTION] = {0};
PinMask motorStages[4] = {0};

#define MOTOR_TIMERS_I 1 //1
#define MOTOR_TIMERS_J 2 //2
MotorTimerTask motorTimers[MOTOR_TIMERS_I][MOTOR_TIMERS_J] = {0};
volatile int motorAvailableTimers = 0;
volatile int isMotorRunning = false;
int totalMotorTimers = 0;

MotorState newMotorStates[12] = {0};

//MotorState motors[10] = {0};


int16_t lastRecCentiDegrees[TOTAL_MOTORS] = { 0 } ;

//QueueHandle_t motorQueue;






void configMotorPins()
{

    gpio_config_t io_conf;
    io_conf.intr_type = GPIO_INTR_DISABLE;
    io_conf.mode = GPIO_MODE_OUTPUT;
    io_conf.pin_bit_mask = 0;
	io_conf.pin_bit_mask |= BIT64(S_0_PIN) | BIT64(S_1_PIN) | BIT64(S_2_PIN) | BIT64(MOTA_PIN) | BIT64(MOTB_PIN) | BIT64(MOTSLEEP_PIN);
    io_conf.pull_down_en = 0;
    io_conf.pull_up_en = 0;
    ESP_ERROR_CHECK(gpio_config(&io_conf));


	ESP_ERROR_CHECK(gpio_set_level(S_0_PIN, 0));
	ESP_ERROR_CHECK(gpio_set_level(S_1_PIN, 0));
	ESP_ERROR_CHECK(gpio_set_level(S_2_PIN, 0));
	ESP_ERROR_CHECK(gpio_set_level(MOTA_PIN, 0));
	ESP_ERROR_CHECK(gpio_set_level(MOTB_PIN, 0));
	ESP_ERROR_CHECK(gpio_set_level(MOTSLEEP_PIN, 0));

}
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

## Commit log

2025-03-07 Initial Commit.
    [Aditional_Items.csv, BOM_Jaeger.csv, BOM_Jaeger_Driver.csv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]
2026-07-06 Arquivo compactado de peças modeladas pro Robô
2026-10-01 Novos modelos 3d
    [arm_left_1.stl, arm_left_2.stl, arm_right_1.stl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]
